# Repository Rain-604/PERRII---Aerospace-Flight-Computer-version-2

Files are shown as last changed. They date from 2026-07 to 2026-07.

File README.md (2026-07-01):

# PERRII – Aerospace Flight Computer version 2

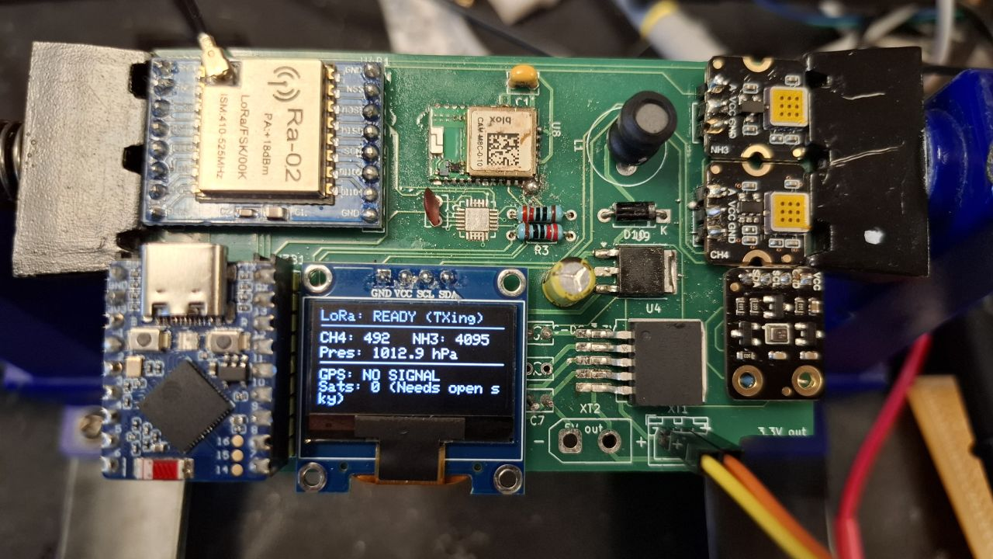
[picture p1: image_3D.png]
3D Render


## Project Overview
PERRII is a modular aerospace flight computer designed for environmental sensing and long-range data telemetry. The system is built around the ESP32-S3 Zero microcontroller and is designed to function as a scientific payload for high-altitude ballooning or atmospheric research. It integrates precision GNSS positioning, environmental gas sensing (Methane and Ammonia), and a robust power regulation system.

## My Contribution: LoRa Communication Subsystem
As the lead for the communication system, I was responsible for the hardware integration and signal integrity of the long-range telemetry link.

### Key Technical Implementations:
* **RFM98W Integration**: Integrated the RFM98W-433S2 LoRa transceiver to provide a robust, low-power, long-distance communication link between the flight computer and the ground station.
* **RF Hardware Design**: Designed the antenna interface for the AE1 Antenna, including a 100pF decoupling capacitor (C5) to ensure signal stability.
* **SPI Interface Management**: Configured the SPI bus (MOSI, MISO, SCK, NSS) to interface the RF module with the ESP32-S3, managing critical interrupt lines (DIO0-DIO5) for real-time packet handling.
* **RF Layout Optimization**: Optimized the trace routing between the RF transceiver and the antenna connector to maintain signal integrity in a compact, circular PCB form factor.

## System Architecture
While my primary focus was the communication link, I worked closely with the team to integrate the following subsystems:

### 1. Navigation & Sensing
* **GNSS Positioning**: Integration of a u-blox CAM-M8C-D GPS module for real-time tracking.
* **Environmental Monitoring**: Active monitoring of atmospheric data via SEN1 (Methane) and SEN2 (Ammonia) gas sensors.
* **Visual Telemetry**: A dedicated LED altitude output array driven by the AW9523B LED driver.

### 2. Power Management
* **Dual-Stage Regulation**: The system utilizes a high-efficiency LM2596S-5 switching buck converter for the primary 5V rail and an LM1117DT-3.3 LDO for the sensitive logic and RF rails.
* **Robust Input**: Featuring XT-30 battery connectors and reverse polarity protection via a D10 Schottky diode.

## Design Files
### 1. Schematic Design
The schematic follows a modular design separated into Power, TX, Sensor, and GPS blocks.

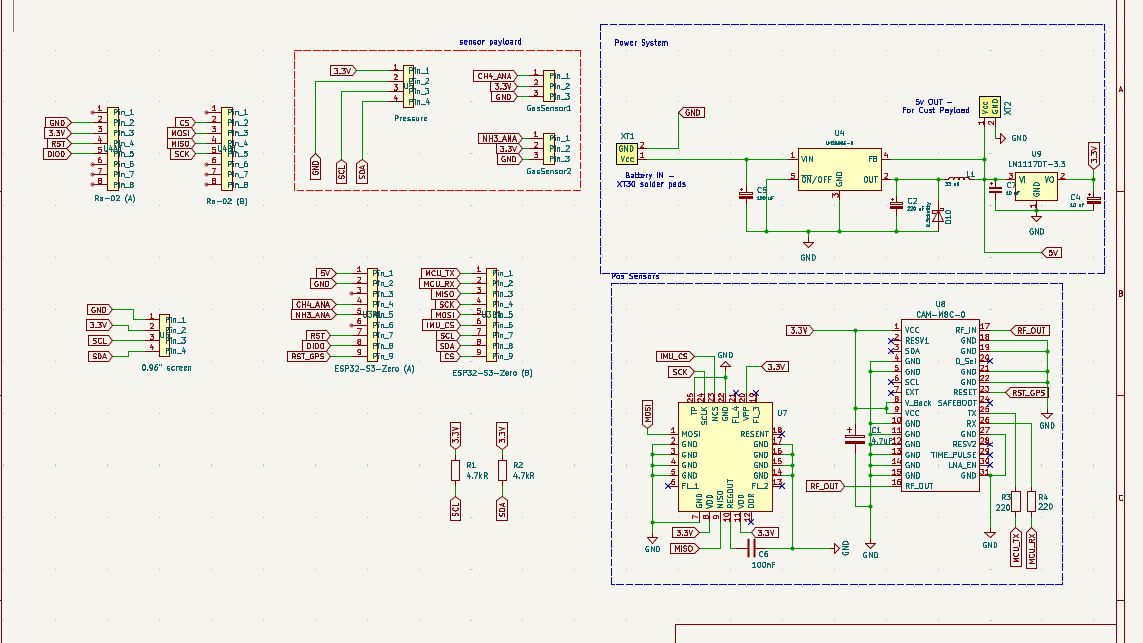
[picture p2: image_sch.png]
Schematic View


### 2. PCB Layout
A circular 2-layer board designed for cylindrical aerospace housing.

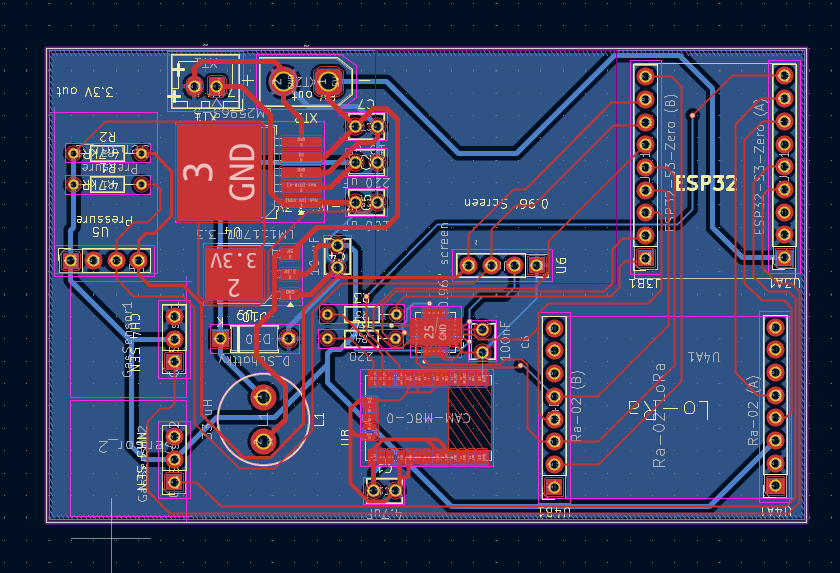
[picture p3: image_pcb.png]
PCB Layout


## Team & Credits
* **Lok Yu Lui (Rain)**: Hardware Engineer – LoRa Communication Subsystem, Power Systems, and Sensor Payloads.
* **PERRII Team**: Collaborative effort for MCU integration and software.

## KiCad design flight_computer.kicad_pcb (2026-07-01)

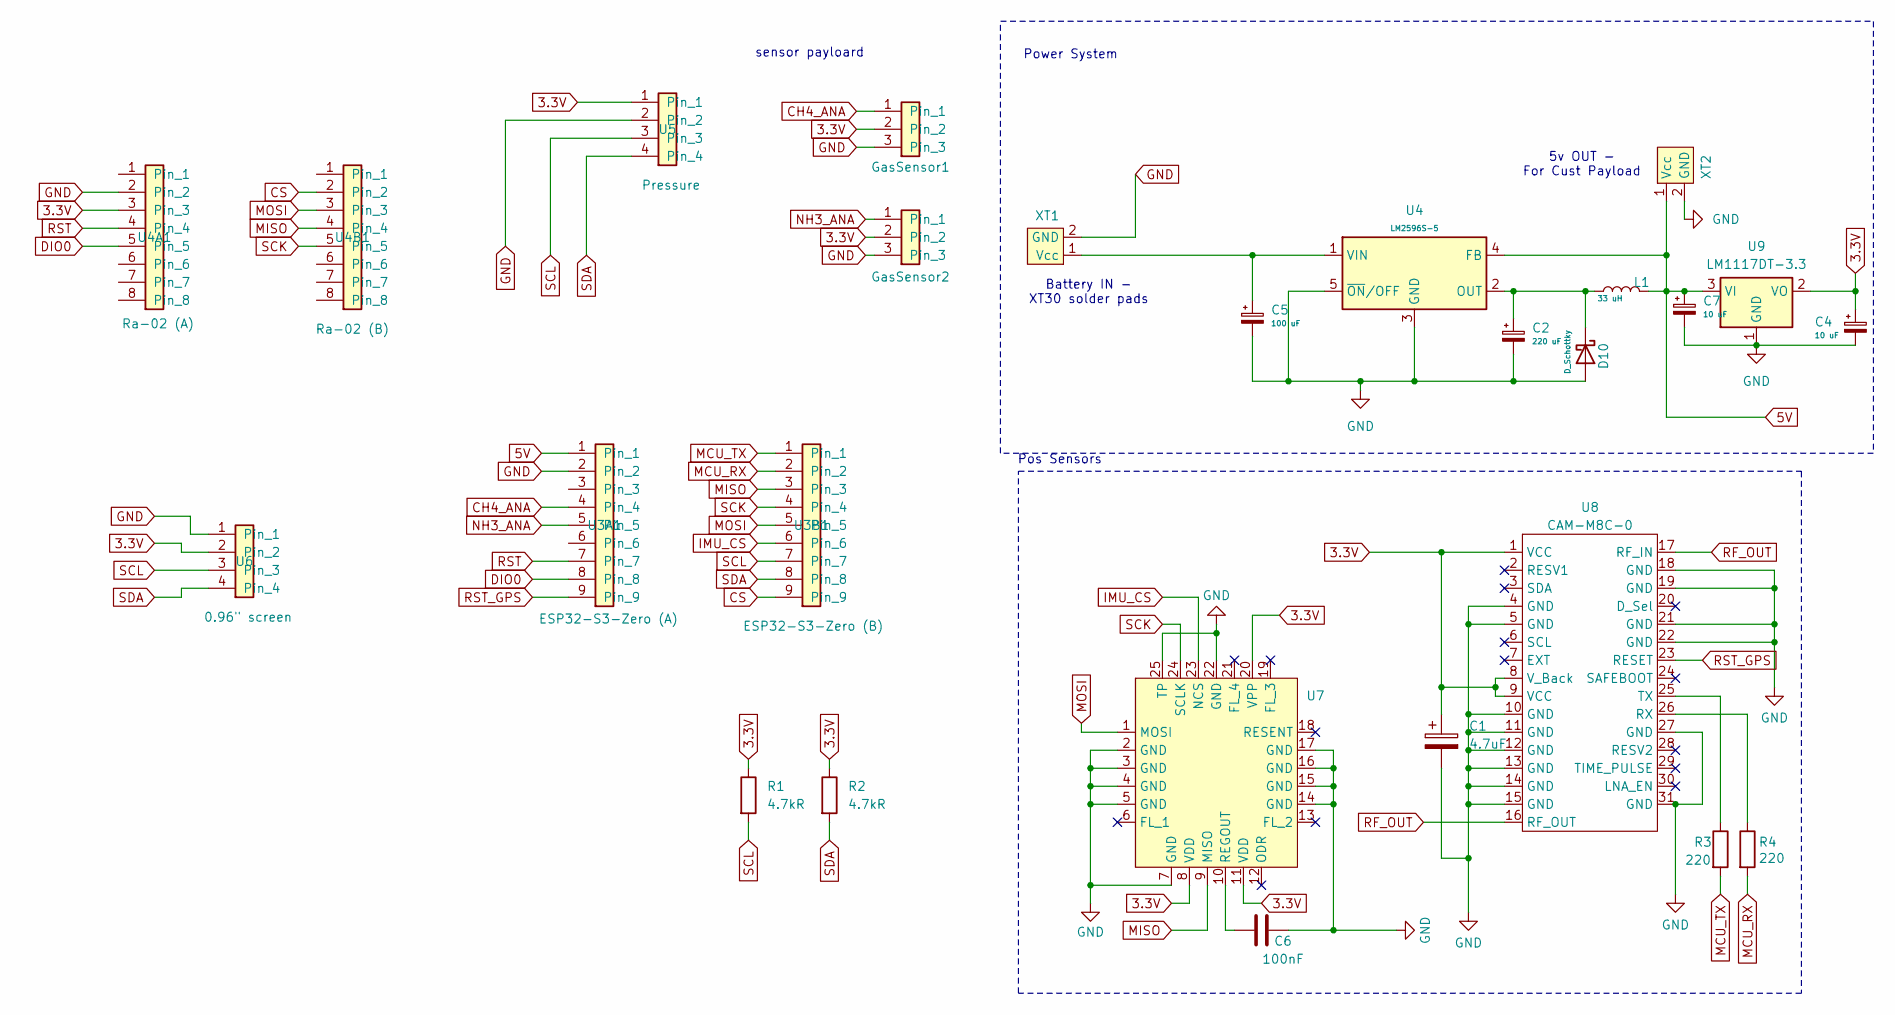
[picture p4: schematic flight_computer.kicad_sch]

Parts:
C1: 4.7uF; C_Disc_D3.8mm_W2.6mm_P2.50mm
C2: 220 uF; C_Disc_D3.8mm_W2.6mm_P2.50mm
C4, C7: 10 uF; C_Disc_D3.8mm_W2.6mm_P2.50mm
C5: 100 uF; C_Disc_D3.8mm_W2.6mm_P2.50mm
C6: 100nF; C_Disc_D3.8mm_W2.6mm_P2.50mm
D10: D_Schottky; D_A-405_P7.62mm_Horizontal
GasSensor1: GasSensor1; PinSocket_1x03_P2.54mm_Vertical
GasSensor2: GasSensor2; PinSocket_1x03_P2.54mm_Vertical
L1: 33 uH; L_Radial_D10.0mm_P5.00mm_Fastron_07P
R1, R2: 4.7kR; R_Axial_DIN0204_L3.6mm_D1.6mm_P7.62mm_Horizontal
R3, R4: 220; R_Axial_DIN0204_L3.6mm_D1.6mm_P7.62mm_Horizontal
U3A1: ESP32-S3-Zero (A); PinSocket_1x09_P2.54mm_Vertical
U3B1: ESP32-S3-Zero (B); PinSocket_1x09_P2.54mm_Vertical
U4: LM2596S-5; TO-263-5_TabPin3
U4A1: Ra-02 (A); PinSocket_1x08_P2.54mm_Vertical
U4B1: Ra-02 (B); PinSocket_1x08_P2.54mm_Vertical
U5: Pressure; PinSocket_1x04_P2.54mm_Vertical
U6: 0.96" screen; PinSocket_1x04_P2.54mm_Vertical
U7: QFN50P450X450X115-25N
U8: CAM-M8C-0; MODULE_CAM-M8C-0
U9: LM1117DT-3.3; TO-252-3_TabPin2
XT1: JST_XH_B2B-XH-A_1x02_P2.50mm_Vertical
XT2: AMASS_XT30UPB-F_1x02_P5.0mm_Vertical

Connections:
3.3V: C1.1, C4.1, GasSensor1.2, GasSensor2.2, R1.1, R2.1, U4A1.3, U5.1, U6.2, U7.8 (VDD), U7.11 (VDD), U7.20 (VPP), U8.1 (VCC), U8.8 (V_Back), U8.9 (VCC), U9.2 (VO)
5V: C7.1, L1.2, U3A1.1, U4.4 (FB), U9.3 (VI), XT2.1 (Vcc)
CH4_ANA: GasSensor1.1, U3A1.4
CS: U3B1.9, U4B1.2
DIO0: U3A1.8, U4A1.5
GND: C1.2, C2.2, C4.2, C5.2, C6.1, C7.2, D10.2 (A), GasSensor1.3, GasSensor2.3, U3A1.2, U4.3 (GND), U4.5 (~ON/OFF), U4A1.2, U5.2, U6.1, U7.2 (GND), U7.3 (GND), U7.4 (GND), U7.5 (GND), U7.7 (GND), U7.14 (GND), U7.15 (GND), U7.16 (GND), U7.17 (GND), U7.22 (GND), U7.25 (TP), U8.4 (GND), U8.5 (GND), U8.10 (GND), U8.11 (GND), U8.12 (GND), U8.13 (GND), U8.14 (GND), U8.15 (GND), U8.18 (GND), U8.19 (GND), U8.21 (GND), U8.22 (GND), U8.27 (GND), U8.31 (GND), U9.1 (GND), XT1.2 (GND), XT2.2 (GND)
IMU_CS: U3B1.6, U7.23 (NCS)
MCU_RX: R4.2, U3B1.2
MCU_TX: R3.2, U3B1.1
MISO: U3B1.3, U4B1.4, U7.9 (MISO)
MOSI: U3B1.5, U4B1.3, U7.1 (MOSI)
NH3_ANA: GasSensor2.1, U3A1.5
unnamed: C2.1, D10.1 (K), L1.1, U4.2 (OUT)
unnamed: C5.1, U4.1 (VIN), XT1.1 (Vcc)
unnamed: C6.2, U7.10 (REGOUT)
unnamed: R4.1, U8.26 (RX)
unnamed: R3.1, U8.25 (TX)
RF_OUT: U8.16 (RF_OUT), U8.17 (RF_IN)
RST: U3A1.7, U4A1.4
RST_GPS: U3A1.9, U8.23 (RESET)
SCK: U3B1.4, U4B1.5, U7.24 (SCLK)
SCL: R1.2, U3B1.7, U5.3, U6.3
SDA: R2.2, U3B1.8, U5.4, U6.4

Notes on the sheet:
Power System
5v OUT - For Cust Payload
sensor payloard
Pos Sensors
Battery IN - XT30 solder pads

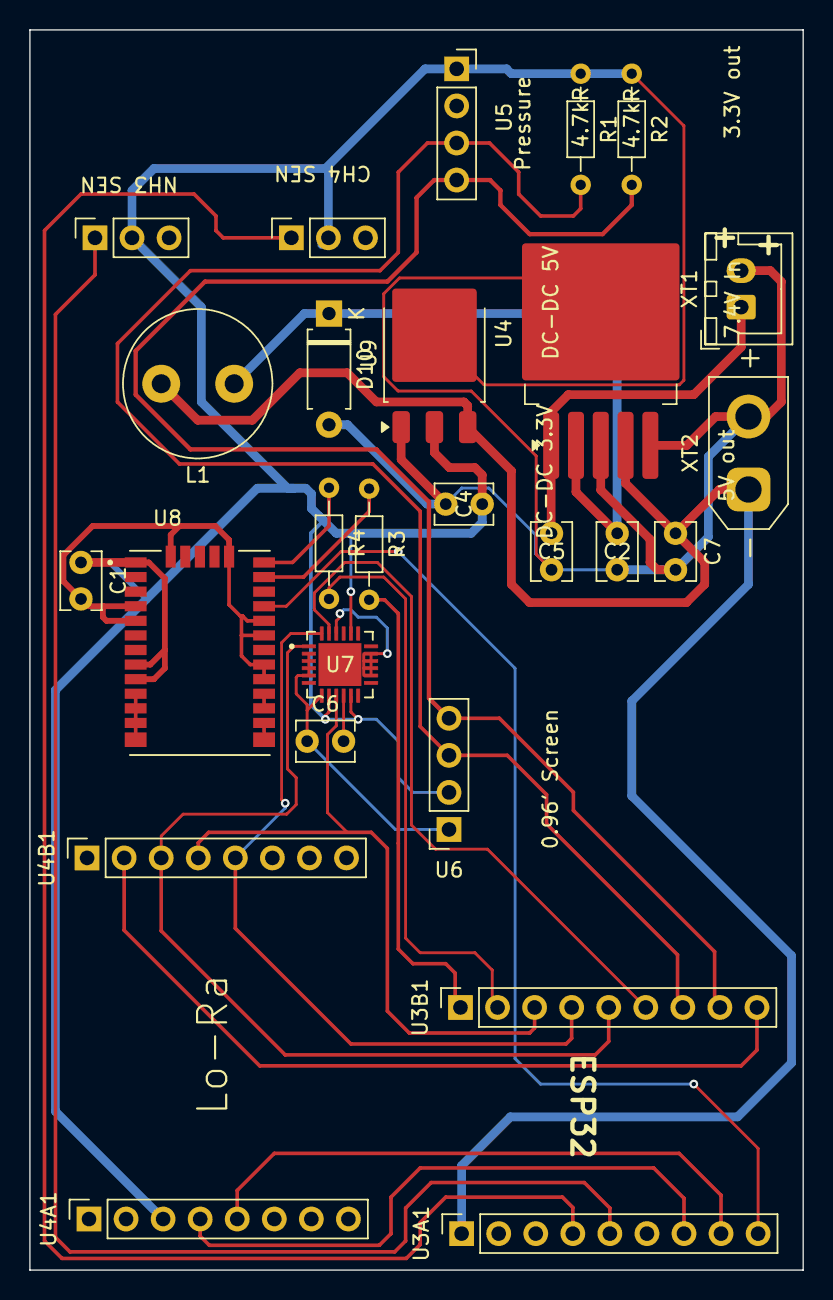
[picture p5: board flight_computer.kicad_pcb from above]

Board: 2 copper layers, 53.0 x 85.0 mm, 30 parts (0 on the bottom side), 23 nets.

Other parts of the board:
S1: Sensor_1; PinSocket_1x02_P2.54mm_Vertical
S2: Sensor_2; PinSocket_1x02_P2.54mm_Vertical
S3: Sensor_3; PinSocket_1x02_P2.54mm_Vertical
U4A1#2: Ra-02 LoRa; PinSocket_1x08_P2.54mm_Vertical
